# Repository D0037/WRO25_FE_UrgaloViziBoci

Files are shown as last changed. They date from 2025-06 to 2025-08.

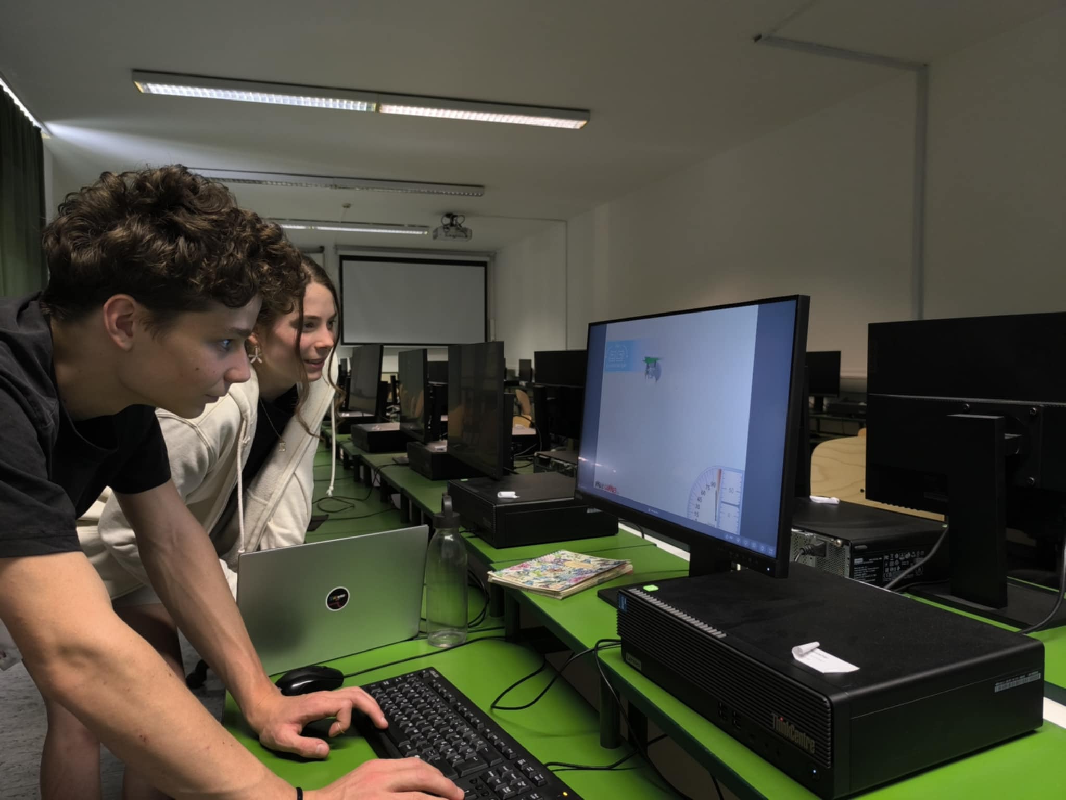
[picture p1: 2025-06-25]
other/moral_documentation/Messenger_creation_820493AD-45BF-424E-ADD0-637CC20AF773.jpeg

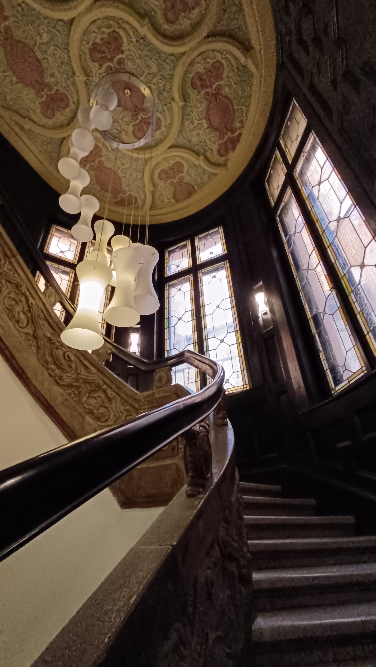
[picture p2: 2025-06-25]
other/moral_documentation/IMG_20250618_110100.jpg

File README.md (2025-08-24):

# WRO 2025 Future Engineers Robot – "Úrgálo Vizí Bóczy"

## 1. Introduction

### 1.1 Team Overview

**Team Name**: FRT Vizí Bóczy
**School**: Budapesti Fazekas Mihály Gimnázium, Budapest

**Team Members**:

- **Márton Serényi** – 10th grade 
  - Responsibilities: Software and Hardware Development
  - Fun fact: Built an audio amplifier at home out of boredom
- **Csenge Veronika Szabó-Komoróczki** – 11th grade 
  - Responsibilities: Documentation and Data Visualization
  - Fun fact: Loves the cat-themed VSCode color scheme

**Team Mentor**:

- **Mariann Sásdi** – Informatics Teacher 
  - Responsible for communication with competition organizers
  - Loved by her students, and always up for a trip with them

### 1.2 Mission Objectives

Our project’s goal is to design and build an autonomous miniature car and participate in the **WRO Future Engineers 2025** competition. We aim to complete the required driving challenges while learning advanced robotics, teamwork, and engineering skills.

The robot’s uniqueness lies in its hybrid sensing approach: using both **TOF LIDAR sensors** and a **mouse optical sensor** for odometry and localization. Combined with a Raspberry Pi 5 and a modular software stack, this provides robust and adaptable navigation.

Success will be defined as:

- Completing the autonomous driving challenges reliably.
- Gaining technical knowledge and problem-solving skills.
- Having fun and creating lasting memories as a team.

---

## 2. Car Description

### 2.1 System Overview

The Úrgálo Vizí Bóczy robot is designed to complete two major challenges:

**Challenge 1 – Open Track**:

- Camera detects track lines (orange and blue) using HSV filtering.
- Calculates intersection point to determine initial position and orientation.
- Uses **TOF distance sensors** and **gyroscope** for odometry (mouse sensor not used in this challenge).
- Follows programmed logic of turns and straight sections to complete 3 laps.

**Challenge 2 – Obstacle Course**:

- Starts from parking using predefined logic and the help of the TOF sensors.
- Checks each segment for obstacles via camera + TOF.
- If obstacle detected → avoidance maneuver based on wall-side or center-side entry.
- Uses both **TOF sensors** and **mouse odometry** (for accurate displacement).
- Executes calibrated turns and maneuvers in real-time, adapting to prior segment data.

---

### 2.2 Hardware Components

| Component | Function | Type / Model | Mounting / Notes |
|---|---|---|---|
| **Main Controller**  | Processing Unit | Raspberry Pi 5 | Custom PLA-printed frame + custom RPi header PCB |
| **Motor Controller** | H-Bridge Motor Driver | [BTS7960-M](https://www.hestore.hu/prod_10038105.html) | Integrated into 3D-printed frame, cooled by dedicated fan |
| **Camera** | Computer Vision | Raspberry Pi Camera Module 3 Wide | Mounted on 3D-printed tower |
| **Gyroscope** | Orientation Sensing | [BNO085 Breakout board](https://www.hestore.hu/prod_10044901.html) | Connected via custom RPi header PCB |
| **Mouse Sensor** | Odometry | Genius smth | 3D-printed plate, hot glued to the half disassembled mouse, the plate can slide up and down, on metal rods |
| **DC Motor** | Drive Power | 1× RC motor (Maverick Strada) | Integrated in original RC chassis |
| **Servo** | Steering | RC Servo | Original RC chassis element |
| **Battery** | Power Source | KAVAN Li-Po 2200mAh, 11.1V, 40/80C, 24.4Wh | Mounted in custom printed holder, routed via power distribution PCB and main switch |
| **Buck Converters**  | Voltage Regulation | 2× 5V USB (Raspberry Pi, servo) + 1× [high-current adjustable voltage converter](https://www.hestore.hu/prod_10043537.html) | Mounted in 3D Printed frame, cooled with small heatsinks; motor converter cooled with 12V 50mm fan |
| **TOF Sensors** | Lateral Distance Measurement | 3× VL53L1X Breakout board | Mounted laterally into printed frame |
| **Voltage Monitor**  | Current/Voltage Sensing | ADS1115 | Connected on custom RPi header PCB |
| **Frame + Wheels** | Mechanical Base | Modified RC car chassis with 3D-printed add-ons | Sturdy, custom-designed mounts |
| **Custom PCBs** | Power + Sensor Interfaces | 1× Power distribution PCB (battery, motor, switch) + 1× RPi HAT PCB (sensors, start/reset) | Mounted on 3D-printed frame |
| **Decoration** | Team Mascot | 3D-printed cow figure | Mounted at the front of the robot |

---

### 2.3 Mechanical / Structural Design

- **Base Frame**: Modified RC car chassis with PLA add-ons.
- **3D-printed structures**: Mounts for Pi, converters, sensors, camera, motor controller and battery.
- **Camera tower**: Mounted on 3D-printed column.
- **Mouse sensor**: Under chassis with custom PLA holder.
- **Cooling system**: Motor converter cooled with fan; other converters with heatsinks.
- **Decoration**: Mascot cow 3D-printed on the front.

Mounting is done by M3 screws, on small parts hotglue.

---

### 2.4 Electrical Design

We wanted a clean desing, so we custom designed two PCBs.

1. One handles the power, converts it to 5V for the electronics
2. The second one is a custom Raspberry Pi HAT, that connects the sensors, the servo and the motorcontroller to the RPi.

- **Power**: KAVAN 11.1V Li-Po → distributed via custom power PCB.
- **Buck converters**: 5V for RPi & servo; and a [high-current adjustable voltage converter](https://www.hestore.hu/prod_10043537.html) to supply consistent voltage to the motor.
- **Main switch + buttons**: Easy operation control.
- **Sensors**: Connected via RPi header PCB.
- **Motor controller**: [BTS7960-M](https://www.hestore.hu/prod_10038105.html) H-bridge motor controller

#### 2.4.1 5V buck converters

- <https://www.hestore.hu/prod_10041976.html>
- They step down DC voltage to 5V for the electronics and servo.
- One is connected to the pi, the other one powers the servo. In previous iterations of the robot, the use of a single buck converter lead to it over-heating, causing the Pi to shut down.

#### 2.4.2 High-current buck converter

- Supplies constant voltage to the motor.
- It is mandatory for consistent runs, because of the non-constant battery voltage.

#### 2.4.3 Feedback LEDs

- They provide visual feedback.
- They are connected to GPIO pins on the Pi, in series with current limiting resistors.

#### 2.4.3 Buttons

- It provides an easy way of starting and stopping the robot
- They are connected to GPIO pins, which are pulled high internally in the Pi.
- When they are pressed, they connect the GPIO pins to ground, via some 330 Ohm resistors, which are there to prevent shorting Pi by a programming mistake.

#### 2.4.4 Gyroscope

- To select SPI mode one it's PS0 pin has to be pulled high, and a pull down resistor has to be removed from the breakout board

#### 2.4.5 Motor controller

- It is controlled by a PWM signal produced by the Raspberry Pi.
- Two enable pins have to be HIGH to enable both halfs of the H-Bridge driver.
- It has current sense pins, which output current proportional to the motor current. They are connected through 1k resistor ground, which allows as to measure the voltage drop on the resistor with an ADC, and calculate the current flowing through the motor.

(PCB designs and electrical drawing are located in the  `/schemes/` folder.)

---

### 2.5 Software Design

- **Language**: Python (OpenCV, sensor control) + C++ (gyro backend).
- **Modules**: 
  - Position tracking (mouse + gyro fusion) wirtten in C++
  - Image processing (OpenCV)
  - ToF sensor data processing
  - Motion controller (PWM signals for motor + servo)
  - PID-based steering corrections

Some modules run as concurrent threads on Raspberry Pi 5. The robot does not log data long-term; decisions are made in real-time.

**Flowcharts:**

- **System Startup**: Power on → Initialize sensors → Calibration → Ready.
- **Challenge 1 Flow**: Vision detects track → ToF sensors → Follow path → 3 laps → Stop.
- **Challenge 2 Flow**: Exit parking → Obstacle detection → Wall-side/Center-side avoidance logic → Loop until finish.
- **Software Architecture**: Multithreaded modules (Vision, Odometry, Controller) feeding into main decision loop.

---

## 3. Competition Backup Strategy

### Spare Parts

- 1× Li-Po Battery (KAVAN 2200mAh 11.1V)
- 1× TOF400C-VL53L1X sensor
- 1× 5V Buck Converter
- 1x Adjustable voltage high-current buck converter (for the motor)
- We also wanted to bring a backup motor controller, but it was sadly needed during tesing.

### Tools and Repair Equipment

- Soldering station
- Hot glue gun
- Full toolbox (pliers, screwdrivers, cutters)
- Extra jumper wires and cables

---

## 4. Summary

The **FRT Vizí Bóczy** team has built an innovative robot for the WRO Future Engineers 2025 challenge. The robot combines **TOF sensors, optical odometry, and vision** to navigate both open tracks and obstacle courses. Built on a recycled RC chassis with custom 3D-printed parts and PCBs, the robot reflects a balance of creativity, engineering, and practical problem-solving.

Our greatest achievement is not just a working robot but the **knowledge gained and teamwork developed** throughout the process.

Odometry is the use of data from motion sensors to estimate change in position over time. It is used in robotics by some legged or wheeled robots to estimate their position relative to a starting location. This method is sensitive to errors due to the integration of velocity measurements over time to give position estimates. Rapid and accurate data collection, instrument calibration, and processing are required in most cases for odometry to be used effectively. [Wikipedia](https://en.wikipedia.org/wiki/Odometry)

---

**Maintained and presented by Team Úgráló Vizíbóczy**\
Hungary — WRO 2025 Future Engineers Division

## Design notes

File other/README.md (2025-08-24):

# Documentation of the testing end debugging process

## - WRO25_FE\_Úrgaló Vizí Bóczy -

This section provides a summary of the key issues we encountered during development and how we resolved them. Each problem is followed by our solution and technical or creative choices that led to a working implementation.

---

## Gyroscope

**Problem:**  
We wanted to communicate with the gyro over SPI, but the single library that supportsthe BNO085 on a Raspberry PI had a broken SPI functionality. And since we have already ordered the custom designed PCBs, we couldn't use I2C.

**Solution:**  
We used Adafruit's Arduino library for the sensor as a base, and rewrote the hardware hardware abstraction layer, to get it working on a Raspberry Pi.

---

## Hardware PWM & Software PWM

**Problem:**  
The Raspberry Pi 5 provides only two hardware PWM channels, which was insufficient for all components (we needed PWM for the servo and both directions of the motor controller).

**Solution:**  
We prioritized precision for the steering servo and assigned it a hardware PWM channel. The DC motors were driven using software PWM, which, while less accurate, was sufficient for propulsion.  
Configuring hardware PWM on the RPi 5 was non-trivial, but after overcoming driver and pin assignment challenges, we achieved a stable setup.

---

# Maintained and presented by Team Úgrálo Vizí Bóczy

Hungary — WRO 2025 Future Engineers Division — 2025.06.25.

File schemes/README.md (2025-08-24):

Electromechanical diagrams
====

**We have custom designed two PCBs for our robot.**

1. Pi Hat style PCB for sensors and motor controller connections to the Raspberry Pi via the 40 pin GPIO header.
2. A simple PCB made for power distribution.

## Pi Hat Circuit diagram
Circuit Diagram

## Power distribution board
![Power distribution board](power_distribution.svg]

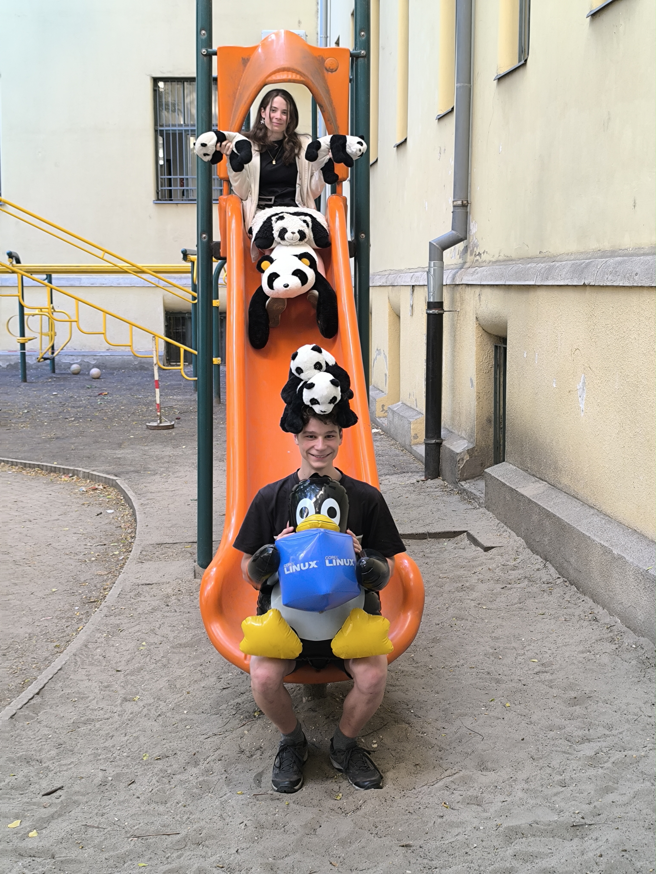
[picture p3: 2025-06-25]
t-photos/WRO_komolytalan.jpg

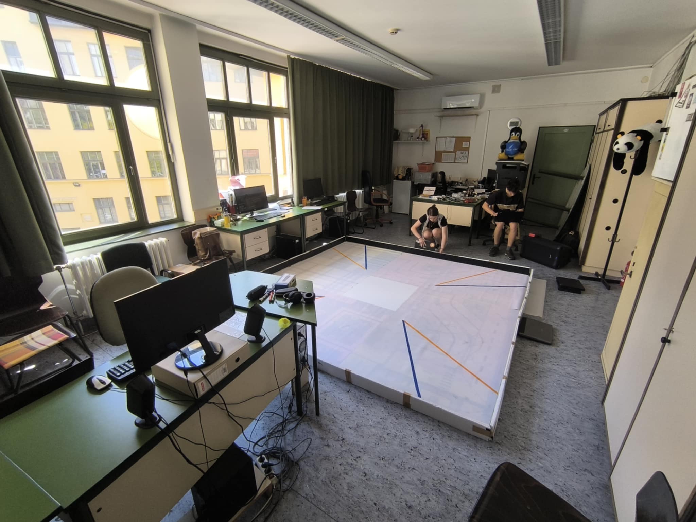
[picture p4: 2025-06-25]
other/moral_documentation/Messenger_creation_066AF94A-1A25-4758-8639-8ACCCD3FD8EA.jpeg

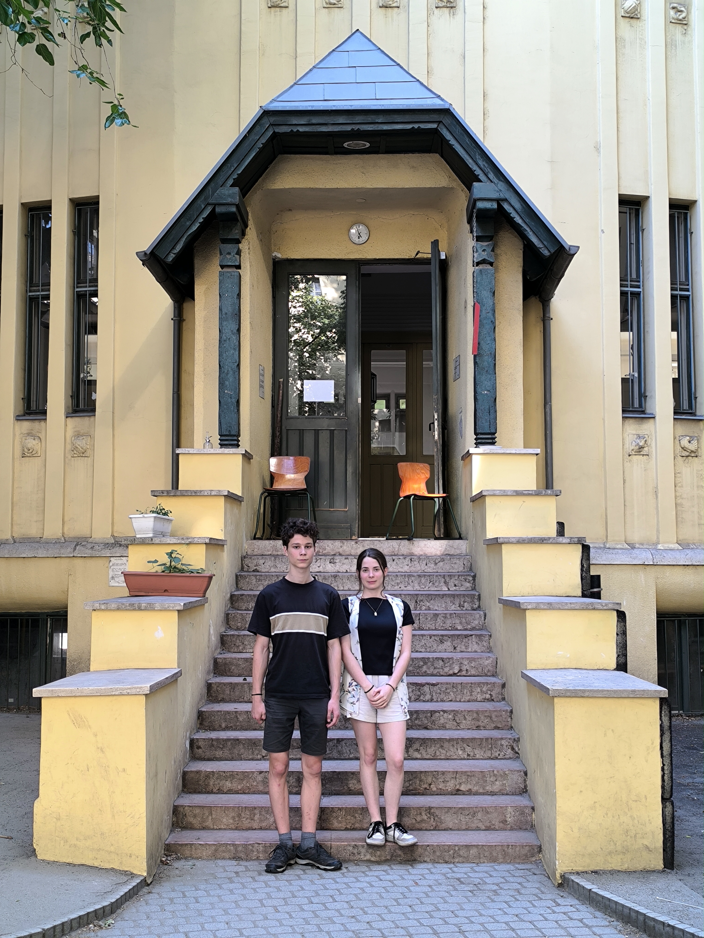
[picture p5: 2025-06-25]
t-photos/WRO_komoly.jpg

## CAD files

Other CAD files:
other/3D/WRO_Lego_Part.x_t
other/3D/WRO_Platform.x_t

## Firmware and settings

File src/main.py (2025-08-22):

#code for running and connecting the whole project
import utils.movement as move
import time
import threading
import utils.image_processing as processing
import os
import signal
import round2
import RPi.GPIO as GPIO
import config
import utils.sensors as sensors

#starting thread
GPIO.setmode(GPIO.BCM)

sensors.init()

image_thread = threading.Thread(target=processing.image_thread)
image_thread.start()

do_sleeps = True

def sleep(time):
    if do_sleeps:
        time.sleep(time)

#processing.set_mode("parking")
move.init()

mode = "obstacle"

def start(channel):
    try:
        #setup for first round
        if mode == "free":
            processing.set_mode("start_pos")
            move.tracker.gyro.reset()
            move.tracker.reset()
            x, y, z = 0, 0, 0

            #set pos
            while (not processing.lines):
                time.sleep(0.001)
            pos = processing.start_pos
            print("START_POS", pos)
            processing.set_mode("none")
            # processing.kill = True

            # custom moving behaviors
            if pos == "front_outer": x, y, side = 40, 70, 150   #1
            if pos == "front_middle": x, y, side = 57, 50, 155  #2
            if pos == "front_inner": x, y, side = 35, 60, 115   #3
            if pos == "back_outer": x, y, side = 65, 70, 152  #4
            if pos == "back_middle": x, y, side = 92, 50, 155 #5
            if pos == "back_inner": x, y, side = 80, 60, 117.5 #6
            print("START_POS", pos)

            # dealing with directions
            z = 0
            if processing.direction: z = -90            
            else: z = 90

            # moving through the first round challange
            def first(x:float, y:float, z:float):
                move.move(x + 20)
                move.turn(z, y)
                move.move(side)
                #time.sleep(5)

                for i in range(10):
                    move.turn(z, 60)
                    move.move(140)
                    move.global_angle -= 1.16 * (z / abs(z))
                    #time.sleep(5)

                move.turn(z, 60)
                move.move(70, 12)
            
            first(x, y, z)
            #move.move(70)
            #move.turn(-90, 50, forward=-1)
        
        #setup for second round
        elif mode == "obstacle":
            processing.set_mode("start_pos")
            time.sleep(2)
            d = 1
            if processing.direction:
                d = -1
            processing.set_mode("1st_obstacle")
            time.sleep(2)
            processing.set_mode("none")
            block = processing.first_block

            # Left turns
            if (d == -1):
                move.set_angle(40)
                move.set_speed(10)
                time.sleep(0.8)

                move.set_angle(-40)
                time.sleep(0.8)
                
                move.set_speed(10)
                move.set_angle(0)
                time.sleep(0.5)

                move.set_angle(-60)
                move.set_speed(20)
                time.sleep(0.62)

                move.set_angle(0)
                time.sleep(3)

                move.set_speed(-15)
                time.sleep(1.4)

                move.set_angle(0)
                move.set_speed(0)

                for i in range(11):
                    move.set_angle(-60)
                    move.set_speed(20)
                    time.sleep(1.2)

                    move.set_angle(0)
                    time.sleep(3)

                    move.set_speed(-15)
                    time.sleep(1)

                    move.set_angle(-60)
                    move.set_speed(20)
                    time.sleep(0.8)


            # Right turns
            else:
                move.set_speed(10)
                move.set_angle(-20)
                time.sleep(0.5)

                move.set_angle(0)
                time.sleep(2)

                move.set_angle(20)
                time.sleep(0.5)

                move.set_angle(0)
                move.set_speed(20)
                time.sleep(0.2)

                move.set_angle(60)
                time.sleep(0.8)

                move.set_angle(0)
                time.sleep(3)

                for i in range(11):
                    move.set_speed(-15)
                    time.sleep(1)
                    
                    move.set_angle(60)
                    move.set_speed(20)
                    time.sleep(0.8)

                    move.set_angle(0)
                    time.sleep(3)


    # for ctrl^C to work during data flow
    except:
        pass
    finally:
        # Finishing arguments
        move.set_speed(0)        # Finishing arguments
        move.set_speed(0)
        move.set_angle(0)

        # Cleanup
        processing.kill = True
        move.cleanup()
        os.kill
        move.set_angle(0)

        # Cleanup
        processing.kill = True
        move.cleanup()
        os.kill(os.getpid(), signal.SIGTERM)


GPIO.add_event_detect(17, GPIO.RISING, start, 200)
try:
    time.sleep(9999999)
except:
    pass
finally:
    move.set_speed(0)
    move.set_angle(0)
    processing.kill = True
    move.cleanup()

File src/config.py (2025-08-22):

# === PIN CONFIIGURATION ===

 #LEDs
LED_READY = 4
LED_WARN = 13

# Buttons
BTN_RST = 23
BTN_START = 24

# TOF LASER
SHUT_LASER_1 = 17
SHUT_LASER_2 = 22
SHUT_LASER_3 = 27

INT_LASER_1 = 16
INT_LASER_2 = 21
INT_LASER_3 = 20

# MOTOR
MOTOR_L_PWM = 5
MOTOR_R_PWM = 6

MOTOR_L_EN = 18
MOTOR_R_EN = 7

SERVO = 12
SERVO_PWM_CHIP = 0

# GYRO
GYRO_INT = 19
GYRO_RST = 26


# === MOVEMENT ===

MOTOR_PWM_FREQ = 1000

# PID
P = 1
I = 0.1
D = 0.4

MOUSE_CONVERSION_RATIO = 500

# === ADC ===
BAT_V_CONVERSION = 1321 / 328

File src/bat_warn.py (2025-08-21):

import ADS1x15
import config
import time
from utils.led import LED
import sys

def get_bat():
    """
    Reads the battery voltage using the ADS1115 ADC.
    The battery is connected to the ADC through a voltage divider.
    """
    ADS = ADS1x15.ADS1115(1)  # or ADS1x15.ADS1015() for 10-bit resolution
    ADS.setMode(ADS.MODE_SINGLE)
    ADS.setDataRate(ADS1x15.ADS1115.DR_ADS111X_8)
    ADS.setGain(ADS.PGA_4_096V) # Max voltage is 12.6V / (1321 / 328) = ~3.12V
    f = ADS.toVoltage()
    voltage = ADS.readADC(0) * f # Read from channel 0

    # Apply the conversion ratio for the voltage divider
    return voltage * config.BAT_V_CONVERSION

# This is used when the script is run by systemd, so an LED can be lit
def warn_bat():
    import RPi.GPIO as GPIO
    GPIO.setmode(GPIO.BCM)

    warn = LED(config.LED_WARN)

    while True:
        if get_bat() < 10:
            warn.on()
        elif get_bat() > 10.1:
            warn.off()
        
        time.sleep(1)
    
if __name__ == "__main__":
    print(get_bat())

    if len(sys.argv) > 1 and sys.argv[1] == "warn":
        warn_bat()

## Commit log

2025-04-25 Added gyro functionality and basic functions
    [pyvenv.cfg]
2025-04-26 Rewritten gyro functionality on C++
2025-06-24 Added documentation
    [WRO_Lego_Part.x_t, WRO_Platform.x_t]
2025-06-24 fixed turning
    [turn.csv]
2025-06-25 Last minute adustions ;)
    [block_1l.csv, block_1r.csv, block_2l.csv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]
2025-06-25 turn fixes pt.n+1
    [turn.csv]
2025-08-21 Added functionality for new hardware
    [pyvenv.cfg]
2025-08-24 Updated docs
    [WRO_Lego_Part.x_t, WRO_Platform.x_t, block_1l.csv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]
